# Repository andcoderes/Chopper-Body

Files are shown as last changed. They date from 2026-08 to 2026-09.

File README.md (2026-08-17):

# Chopper Body V2

## Acknowledgments

This firmware was strongly influenced by the [Amidala](https://github.com/thePunderWoman/Amidala) firmware by [thePunderWoman](https://github.com/thePunderWoman).

ESP32-based body controller for the Chopper robot. Controls drive motors, dome rotation, body servos, MP3 audio, and a bubble machine via ESP-NOW commands from the controller.

## Features

- **MDDS30 drive motors** — PWM Independent mode, differential steering
- **Cytron MD10C dome rotation** — bidirectional speed control
- **Pololu Maestro servos** — scripted body animations via Serial1
- **MP3 audio player** — serial protocol playback via Serial2
- **Bubbles relay** — on/off control
- **ESP-NOW** — encrypted communication with the controller
- **WiFi AP + OTA** — web interface at `chopper.body` for firmware updates
- **Safety timeout** — motors stop after 500ms without commands or on ESP-NOW disconnect

## ESP32 Pin Assignments

| Function | GPIO | Type | Notes |
|---|---|---|---|
| **MDDS30 IN1** (left dir) | 4 | Digital out | LOW = forward, HIGH = reverse. 10k pull-down on board |
| **MDDS30 AN1** (left speed) | 17 | LEDC PWM | 5 kHz, 8-bit. 10k pull-down on board |
| **MDDS30 IN2** (right dir) | 16 | Digital out | LOW = forward, HIGH = reverse. 10k pull-down on board |
| **MDDS30 AN2** (right speed) | 5 | LEDC PWM | 5 kHz, 8-bit. 10k pull-down on board |
| **Cytron MD10C DIR** (dome dir) | 14 | Digital out | 10k pull-down on board |
| **Cytron MD10C PWM** (dome speed) | 27 | LEDC PWM | 5 kHz, 8-bit. 10k pull-down on board |
| **Dome home sensor** | 26 | Digital in | A3144 hall-effect, 10k+20k divider |
| **Dome encoder A** | 25 | Digital in | 10k+20k divider |
| **Dome encoder B** | 33 | Digital in | 10k+20k divider |
| **Pololu Maestro TX** | 32 | Serial1 TX | 9600 baud |
| **Pololu Maestro RX** | 35 | Serial1 RX | Input-only. 1k + 2k voltage divider (5V -> 3.3V) |
| **MP3 Player TX** | 19 | Serial2 TX | 9600 baud |
| **MP3 Player RX** | 18 | Serial2 RX | 1k + 2k voltage divider (5V -> 3.3V) |
| **Bubbles relay** | 21 | Digital out | Relay module, active HIGH |
| **USB Debug TX** | 1 | Serial0 TX | 115200 baud |
| **USB Debug RX** | 3 | Serial0 RX | 115200 baud |

GPIO12 and GPIO13 (previously used for MDDS30) are intentionally left
unconnected — GPIO12 is an ESP32 boot-strapping pin (flash voltage select)
and stray HIGH signals on it during power-up can put the board in a reset
loop. GPIO22/23 (previously Maestro) and GPIO34 (previously dome encoder B)
are also now unused.

### MDDS30 DIP Switch Setting

`0b10110100` — PWM Independent mode. All three hardware UARTs remain free.

### Serial Port Allocation

| UART | GPIO TX | GPIO RX | Baud | Device |
|---|---|---|---|---|
| Serial0 | 1 | 3 | 115200 | USB debug console |
| Serial1 | 32 | 35 | 9600 | Pololu Maestro servo controller |
| Serial2 | 19 | 18 | 9600 | MP3 player module (Catalex-style, requires "select TF card" init) |

## Build

Requires [PlatformIO](https://platformio.org/).

Before your first build, set up ESP-NOW encryption keys — see
[Generating ESP-NOW keys](#generating-esp-now-keys) below. The build will
fail with a clear error if `.env` is missing.

```bash
# One-time setup: copy the template and fill in real keys
cp .env.example .env

# Compile firmware
pio run

# Upload to ESP32
pio run --target upload

# Run unit tests (native)
pio test -e native

# Monitor serial output
pio device monitor
```

## Project Structure

```
pcb/                                  # KiCad project (schematic, board, gerbers)
firmware/
  platformio.ini
  .env.example                       # Template for ESP-NOW keys — copy to .env
  partitions/ota_4MB.csv
  scripts/load_secrets.py            # Pre-build: .env -> include/secrets.h
  scripts/embed_web.py              # Pre-build: inlines CSS into HTML
  web/
    assets/common.css                # Shared styles
    index.html                       # Home page (info + links)
    update.html                      # OTA firmware upload page
  include/
    web_pages.h                      # AUTO-GENERATED by embed_web.py
    secrets.h                        # AUTO-GENERATED by load_secrets.py, gitignored
  src/
    config.h                         # Pin definitions, timeouts (keys come from secrets.h)
    main.cpp                         # Setup/loop, WiFi, command dispatch
    communication/
      MessageTypes.h                 # BodyCommand / BodyTelemetry structs
      EspNowController.h/.cpp        # ESP-NOW encrypted communication
    motor/
      MotorController.h/.cpp         # MDDS30 + L298N motor control
    servo/
      ServoController.h/.cpp         # Pololu Maestro body servos
    audio/
      AudioController.h/.cpp         # Serial MP3 player protocol
    web/
      WebController.h/.cpp           # WiFi AP, OTA updates, info API
      logger.h                       # Serial logging utility
  test/
    mocks/                           # Arduino/ESP32 mock headers
    test_message_types/              # Struct packing and field tests
    test_motor_controller/           # Drive mixing, dome, timeout tests
    test_audio_controller/           # MP3 protocol frame tests
    test_servo_controller/           # Animation state machine tests
    test_esp_now_controller/         # Connection timeout, dispatch tests
```

## ESP-NOW Protocol

### Controller -> Body (msgType = 3, 26 bytes)

| Field | Type | Description |
|---|---|---|
| msgType | int8 | Always 3 |
| status | int8 | 0 = buttons, 1 = movement, 2 = settings, -1 = connection |
| lx | int8 | Drive X axis: -100 to 100 |
| ly | int8 | Drive Y axis: -100 to 100 |
| domeSpeed | int8 | Dome rotation: -100 to 100 |
| audioTrack | uint8 | 0 = none, 1-255 = play track |
| volume | uint8 | 0-30 |
| bubbles | uint8 | 0 = off, 1 = on |
| button | char[8] | Servo button name (e.g. "y", "du") |
| macro | int16[4] | Servo macro IDs |
| connectionStatus | int8 | 0 = disconnected, 1 = connected |
| padding | uint8 | Alignment padding |

### Body -> Controller (msgType = 4, 8 bytes)

| Field | Type | Description |
|---|---|---|
| msgType | int8 | Always 4 |
| connected | uint8 | 1 if ESP-NOW link active |
| motorsActive | uint8 | 1 if drive/dome motors running |
| audioPlaying | uint8 | 1 if audio track playing |
| uptimeMs | uint32 | Milliseconds since boot |

## WiFi Access Point

- **SSID:** ChopperBody
- **IP:** 192.168.5.1
- **mDNS:** chopper-body.local
- **Pages:** `/` (home), `/update` (OTA)
- **API:** `/api/info` (JSON: version, uptime, heap, MAC)

## Generating ESP-NOW keys

This board talks to the other Chopper boards over encrypted ESP-NOW. Before
your first build, generate two 16-byte (128-bit) keys — a Primary Master Key
(PMK) and a Local Master Key (LMK) — and put them in a `.env` file
(gitignored, never commit it) at the project root:

```bash
cp .env.example .env
```

Generate two random 16-byte keys, each as 32 hex characters:

```bash
# Option 1: openssl
openssl rand -hex 16   # run twice — once for PMK_KEY, once for LMK_KEY

# Option 2: python
python3 -c "import secrets; print(secrets.token_hex(16))"
```

Edit `.env` and paste the values in:

```
PMK_KEY=<first random hex string>
LMK_KEY=<second random hex string>
```

**These two keys must be byte-for-byte identical across chopper body,
chopper head, and chopper receiver** — generate them once and copy the same
`.env` values into all three projects. Mismatched keys mean the boards can't
decrypt each other's ESP-NOW packets and the mesh will never connect.

`.env` also holds `CONTROLLER_MAC` — the controller's WiFi MAC address (as
hex, e.g. `C0CDD6CA29E0`), which must likewise be identical across all three
firmware projects — and `WIFI_AP_PASSWORD`, the password for this board's
local OTA-update access point (pick your own, at least 8 characters; unlike
the other values, this one doesn't need to match the other boards).

`scripts/load_secrets.py` runs automatically before every build (see
`platformio.ini`) and turns `.env` into `include/secrets.h`, which
`config.h` includes. Neither `.env` nor the generated `secrets.h` are
committed to git — the build fails with a clear error if `.env` is missing.

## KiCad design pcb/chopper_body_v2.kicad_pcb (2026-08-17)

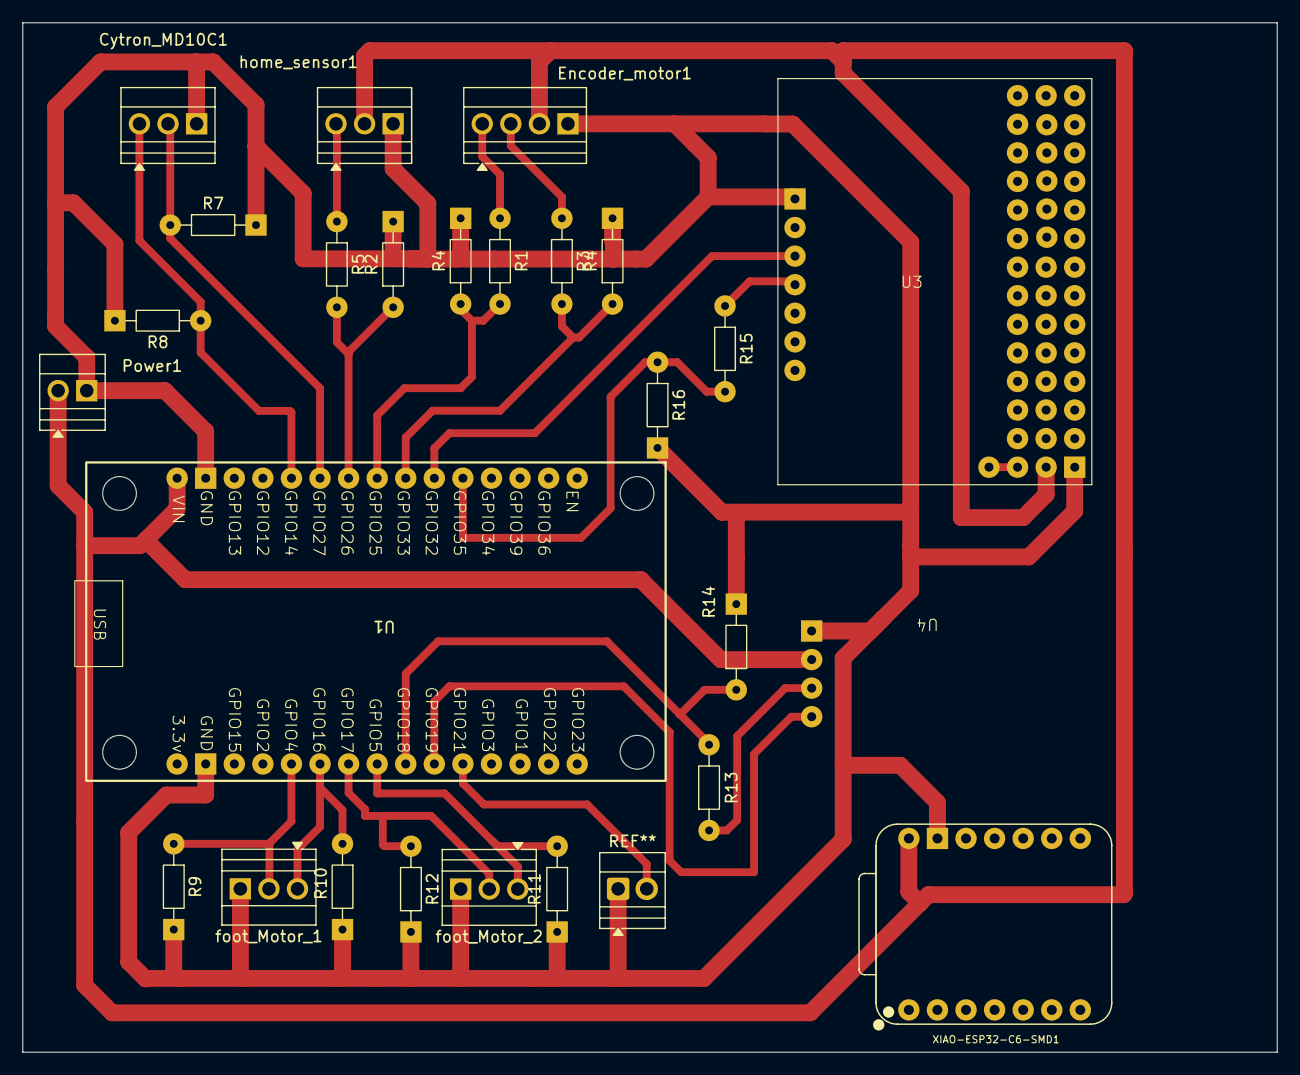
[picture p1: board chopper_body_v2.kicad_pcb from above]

Board: 2 copper layers, 111.5 x 91.5 mm, 26 parts (0 on the bottom side), 21 nets.

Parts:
Cytron_MD10C1: DIR_PWM_GND; TerminalBlock_Xinya_XY308-2.54-3P_1x03_P2.54mm_Horizontal
Encoder_motor1: motor_head_enc_a_enc_b_5v_GND; TerminalBlock_Xinya_XY308-2.54-4P_1x04_P2.54mm_Horizontal
Power1: 5v_GND; TerminalBlock_Xinya_XY308-2.54-2P_1x02_P2.54mm_Horizontal
R1, R3, R5, R7, R8, R9, R10, R11, R12: 10K; R_Axial_DIN0204_L3.6mm_D1.6mm_P7.62mm_Horizontal
R2, R4, R4#2: 20K; R_Axial_DIN0204_L3.6mm_D1.6mm_P7.62mm_Horizontal
R13, R15: 1K; R_Axial_DIN0204_L3.6mm_D1.6mm_P7.62mm_Horizontal
R14, R16: 2K; R_Axial_DIN0204_L3.6mm_D1.6mm_P7.62mm_Horizontal
U1: ESP32_30pin
U3: Pololu_Maestro_12
U4: audio_trigger
XIAO-ESP32-C6-SMD1: XIAO-ESP32-C6-SMD; XIAO-ESP32-C6-DIP
foot_Motor_1: IN1_IN2_GND; TerminalBlock_Xinya_XY308-2.54-3P_1x03_P2.54mm_Horizontal
foot_Motor_2: AN1_IN1_GND; TerminalBlock_Xinya_XY308-2.54-3P_1x03_P2.54mm_Horizontal
home_sensor1: sensor_5v_GND; TerminalBlock_Xinya_XY308-2.54-3P_1x03_P2.54mm_Horizontal

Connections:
+5V: Encoder_motor1.3, Power1.1, U1.1 (VIN), U3.V5In, U4.5V, XIAO-ESP32-C6-SMD1.14 (VBUS), home_sensor1.2
AN1: R12.1, U1.22 (GPIO17), foot_Motor_2.2
AN2: R11.1, U1.23 (GPIO5), foot_Motor_2.1
GND: Cytron_MD10C1.3, Encoder_motor1.4, Power1.2, R2.2, R4.2, R4#2.2, R7.2, R8.2, R9.2, R10.2, R11.2, R12.2, R14.2, R16.2, U1.2 (GND), U1.17 (GND), U3.GNDBoard, U3.GNDIn, U4.GND, XIAO-ESP32-C6-SMD1.13 (GND), foot_Motor_1.3, foot_Motor_2.3, home_sensor1.3
IN1: R9.1, U1.20 (GPIO4), foot_Motor_1.2
IN2: R10.1, U1.21 (GPIO16), foot_Motor_1.1
MD10PWM: Cytron_MD10C1.2, R7.1, U1.6 (GPIO27)
MD10_DIR: Cytron_MD10C1.1, R8.1, U1.5 (GPIO14)
audio_rx: U1.25 (GPIO19), U4.RX
audio_tx: R13.1, U4.TX
audio_tx_resistor: R13.2, R14.1, U1.24 (GPIO18)
encoder_a_resistor: R1.2, R4#2.1, U1.8 (GPIO25)
encoder_a_signal: Encoder_motor1.1, R1.1
encoder_b_resistor: R3.2, R4.1, U1.9 (GPIO33)
encoder_b_signal: Encoder_motor1.2, R3.1
home_sensor_resistant: R2.1, R5.2, U1.7 (GPIO26)
home_sensor_signal: R5.1, home_sensor1.1
pololu_rx: U1.10 (GPIO32), U3.Rx
pololu_tx: R15.1, U3.Tx
pololu_tx_resistor: R15.2, R16.1, U1.11 (GPIO35)
vin_pololu: U3.VSRV, U3.vin

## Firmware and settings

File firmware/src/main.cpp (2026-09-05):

#ifndef UNIT_TEST

#include <Arduino.h>
#include <WiFi.h>
#include <esp_wifi.h>
#include <cstring>
#include "config.h"
#include "communication/EspNowController.h"
#include "communication/MessageTypes.h"
#include "motor/MotorController.h"
#include "dome/DomeController.h"
#include "servo/ServoController.h"
#include "audio/AudioController.h"
#include "web/WebController.h"
#include "web/logger.h"

EspNowController espNow;
MotorController motors;
DomeController dome;
ServoController servo;
AudioController audio;
WebController webController;

bool apActive_ = false;
bool apStartRequested_ = false;
unsigned long bootTime_ = 0;

// Starts the AP + web/captive-portal server. Off by default; only called
// once one of the AP-start conditions is met (see loop()).
void startAP() {
    if (apActive_) return;

    WiFi.softAP(WIFI_AP_SSID, WIFI_AP_PASSWORD);
    WiFi.softAPConfig(IPAddress(192,168,5,1), IPAddress(192,168,5,1), IPAddress(255,255,255,0));

    webController.setDomeController(&dome);
    webController.setup();

    apActive_ = true;
    logAll("AP started, IP: %s", WiFi.softAPIP().toString().c_str());
}

void onCommand(const BodyCommand& cmd) {
    switch (cmd.status) {
        case STATUS_MOVEMENT:
            logAll("ESP-NOW RX: move lx=%d ly=%d dome=%d", cmd.lx, cmd.ly, cmd.domeSpeed);
            motors.setDrive(cmd.ly, -cmd.lx);
            // Dome calibration drives the dome motor itself via dome.loop();
            // an RF movement command here would fight that write.
            if (!dome.isCalibrating()) {
                motors.setDome(cmd.domeSpeed);
            }
            break;

        case STATUS_BUTTONS: {
            logAll("ESP-NOW RX: button='%s' macro=[%d,%d,%d,%d]",
                   cmd.button, cmd.macro[0], cmd.macro[1], cmd.macro[2], cmd.macro[3]);
            int16_t macro[4];
            memcpy(macro, cmd.macro, sizeof(macro));
            servo.animate(cmd.button, macro, 4);
            break;
        }

        case STATUS_CONNECTION:
            logAll("ESP-NOW RX: connection status=%d", cmd.connectionStatus);
            if (cmd.connectionStatus == 0) {
                motors.stopAll();
            }
            break;

        case STATUS_SETTINGS:
            logAll("ESP-NOW RX: settings track=%u vol=%u bubbles=%u",
                   cmd.audioTrack, cmd.volume, cmd.bubbles);
            audio.setVolume(cmd.volume);
            break;

        case STATUS_AP_CONTROL:
            logAll("ESP-NOW RX: AP control requested=%u", cmd.apRequested);
            if (cmd.apRequested) {
                apStartRequested_ = true;
            }
            break;

        default:
            logAll("ESP-NOW RX: unknown status=%d", cmd.status);
            break;
    }

    // Audio and bubbles are handled regardless of status
    if (cmd.audioTrack > 0) {
        audio.playTrack(cmd.audioTrack);
    }
    // cmd.bubbles is the current toggle state from the receiver (see
    // CommandParser), re-stamped onto every packet — just mirror it.
    if (cmd.bubbles) {
        logAll("starting bubbles");
    } else {
        logAll("bubble off");
    }
    digitalWrite(PIN_BUBBLES, cmd.bubbles ? HIGH : LOW);
}

void setup() {
    // Drive every motor pin to a safe stopped state before anything else runs.
    // Until this executes they are undriven inputs; the MDDS30 / MD10C read the
    // floating level as a command and creep a motor during the boot delay below
    // (worst on GPIO16/17, which also toggle at boot on WROVER modules).
    motors.setup();

    // Bubbles relay — same floating-input risk, safe it early too.
    pinMode(PIN_BUBBLES, OUTPUT);
    digitalWrite(PIN_BUBBLES, LOW);

    bootTime_ = millis();

    Serial.begin(115200);
    delay(500);

    dome.setup(motors);
    servo.setup();
    audio.setup();

    // WiFi: AP+STA mode for ESP-NOW + web server coexistence.
    // AP itself stays off (WiFi.softAP not called) until an AP-start
    // condition is met in loop() — see startAP().
    WiFi.mode(WIFI_AP_STA);
    esp_wifi_set_ps(WIFI_PS_NONE);

    espNow.setup();
    espNow.setCommandCallback(onCommand);

    logAll("Chopper V2 Body ready");
}

void loop() {
    // Safety: stop motors on timeout or ESP-NOW disconnect
    motors.checkTimeout();
    if (!espNow.isConnected()) {
        motors.stopAll();
    }

    // Dome encoder / calibration
    dome.loop();

    // Update telemetry state
    espNow.setMotorsActive(motors.isActive());
    espNow.setAudioPlaying(audio.isPlaying());

    // Process ESP-NOW messages and send heartbeat
    espNow.loop();

    // Log any bytes the MP3 module sends back (diagnostics)
    audio.loop();

    // Servo connection check
    if (!servo.isReady()) {
        servo.checkConnection();
    }

    // AP is off by default. Start it if:
    //  - the mesh (ESP-NOW) link hasn't connected within AP_START_TIMEOUT_MS
    //    of boot, or
    //  - a peer over the mesh explicitly requested it (STATUS_AP_CONTROL)
    if (!apActive_) {
        bool meshTimedOut = (millis() - bootTime_ >= AP_START_TIMEOUT_MS) && !espNow.isConnected();
        if (apStartRequested_ || meshTimedOut) {
            startAP();
        }
    }

    // Web server (only serving once the AP is up)
    if (apActive_) {
        webController.loop();
    }
}

#endif // UNIT_TEST

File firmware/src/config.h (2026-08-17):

#pragma once
#include <Arduino.h>

// --- MDDS30 drive motor pins (PWM Independent mode, DIP: 0b10110100) ---
// External pull-down resistors required on all 4 pins: while the ESP32 is
// powering on/off (or resetting) these GPIOs float/default HIGH before
// setup() runs pinMode()/ledcAttachPin(), which the MDDS30 can read as a
// drive command and briefly engage the motors.
#define PIN_MDDS_IN1     4   // Left motor direction (LOW=fwd, HIGH=rev)
#define PIN_MDDS_AN1    17   // Left motor speed (LEDC PWM, 5kHz 8-bit)
#define PIN_MDDS_IN2    16   // Right motor direction (LOW=fwd, HIGH=rev)
#define PIN_MDDS_AN2     5   // Right motor speed (LEDC PWM, 5kHz 8-bit)

// --- Dome encoder + home sensor ---
#define PIN_DOME_ENC_A  25   // Encoder channel A (10k+20k divider)
#define PIN_DOME_ENC_B  33   // Encoder channel B (10k+20k divider)
#define PIN_DOME_HOME   26   // A3144 hall-effect home sensor (HiLetgo module, 10k+20k divider)
#define DOME_ENCODER_CPR 3200 // Counts per motor output shaft revolution (64 CPR * 50:1)
#define DOME_CALIBRATION_SPEED 40 // PWM % for calibration spin
#define DOME_CALIBRATION_TIMEOUT_MS 15000 // Abort calibration if home sensor never fires (safety cutoff)

// --- Cytron MD10C dome rotation motor pins ---
// External 10k pull-down resistors required on both pins (same reason as MDDS30).
#define PIN_DOME_DIR    14   // Dome direction (LOW=fwd, HIGH=rev)
#define PIN_DOME_PWM    27   // Dome speed (LEDC PWM, 5kHz 8-bit)

// --- Pololu Maestro servo controller (Serial1) ---
#define PIN_MAESTRO_TX  32   // Serial1 TX -> Maestro RX (9600 baud)
#define PIN_MAESTRO_RX  35   // Serial1 RX <- Maestro TX (1k+2k divider)

// --- MP3 player (Serial2) ---
#define PIN_MP3_TX      19   // Serial2 TX -> MP3 RX (9600 baud)
#define PIN_MP3_RX      18   // Serial2 RX <- MP3 TX (1k+2k divider)

// --- Bubbles relay ---
#define PIN_BUBBLES     21   // On/off relay module

// --- Secrets (ESP-NOW keys, controller MAC, WiFi AP password) ---
#ifdef UNIT_TEST
// Dummy values for native unit tests — no real ESP-NOW traffic or AP off-device.
static const uint8_t PMK_KEY[16] = {0};
static const uint8_t LMK_KEY[16] = {0};
static const uint8_t CONTROLLER_MAC[6] = {0};
#define WIFI_AP_PASSWORD "test"
#else
#include "secrets.h"  // defines PMK_KEY, LMK_KEY, CONTROLLER_MAC, WIFI_AP_PASSWORD — generated from .env, see README
#endif

// --- Timing constants ---
#define HEARTBEAT_INTERVAL_MS   1000   // How often to send telemetry
#define CONNECTION_TIMEOUT_MS   5000   // No data = disconnected
#define MOTOR_TIMEOUT_MS         500   // Stop motors if no command
#define AP_START_TIMEOUT_MS     3000   // Start AP if mesh not connected by this long after boot

// --- WiFi AP for web server ---
#define WIFI_AP_SSID     "ChopperBody"
// WIFI_AP_PASSWORD comes from secrets.h (generated from .env, see README)

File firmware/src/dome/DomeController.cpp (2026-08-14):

#include "DomeController.h"
#include "../motor/MotorController.h"
#include "../web/logger.h"

volatile int32_t DomeController::encoderCount_ = 0;
volatile bool DomeController::homeTriggered_ = false;

// Guards encoderCount_, shared between onEncoderA() (ISR) and loop()/
// getEncoderCount() (Arduino task). Same portMUX_TYPE pattern used in
// EspNowController for its own ISR/task-shared state.
static portMUX_TYPE encoderMux_ = portMUX_INITIALIZER_UNLOCKED;

void IRAM_ATTR DomeController::onEncoderA() {
    if (digitalRead(PIN_DOME_ENC_B)) {
        encoderCount_ = encoderCount_ - 1;
    } else {
        encoderCount_ = encoderCount_ + 1;
    }
}

void IRAM_ATTR DomeController::onHomeTriggered() {
    homeTriggered_ = true;
}

void DomeController::setup(MotorController& motors) {
    motors_ = &motors;
    encoderCount_ = 0;
    homeTriggered_ = false;
    gearRatio_ = 0.0f;
    state_ = IDLE;

    pinMode(PIN_DOME_ENC_A, INPUT);
    pinMode(PIN_DOME_ENC_B, INPUT);
    pinMode(PIN_DOME_HOME, INPUT);

    attachInterrupt(digitalPinToInterrupt(PIN_DOME_ENC_A), onEncoderA, RISING);
    attachInterrupt(digitalPinToInterrupt(PIN_DOME_HOME), onHomeTriggered, FALLING);

    logAll("Dome encoder + home sensor initialized");
}

void DomeController::startCalibration() {
    if (state_ != IDLE) return;
    homeTriggered_ = false;
    state_ = SEEKING_HOME;
    calibrationStartTime_ = millis();
    // Speed is constant across SEEKING_HOME and ROTATING, so it only needs
    // to be written once here instead of every loop() iteration.
    motors_->setDome(DOME_CALIBRATION_SPEED);
    logAll("Dome calibration: seeking home");
}

bool DomeController::checkCalibrationTimeout(const char* phase) {
    if (millis() - calibrationStartTime_ < DOME_CALIBRATION_TIMEOUT_MS) return false;
    logAll("Dome calibration: timed out %s, aborting", phase);
    motors_->setDome(0);
    state_ = IDLE;
    return true;
}

void DomeController::loop() {
    switch (state_) {
        case IDLE:
            break;

        case SEEKING_HOME:
            if (checkCalibrationTimeout("seeking home")) break;
            if (homeTriggered_) {
                homeTriggered_ = false;
                portENTER_CRITICAL(&encoderMux_);
                encoderCount_ = 0;
                portEXIT_CRITICAL(&encoderMux_);
                state_ = ROTATING;
                calibrationStartTime_ = millis();  // fresh budget for the rotation phase
                logAll("Dome calibration: home found, counting");
            }
            break;

        case ROTATING:
            if (checkCalibrationTimeout("completing rotation")) break;
            if (homeTriggered_) {
                homeTriggered_ = false;
                portENTER_CRITICAL(&encoderMux_);
                int32_t count = encoderCount_;
                portEXIT_CRITICAL(&encoderMux_);
                gearRatio_ = (float)abs(count) / DOME_ENCODER_CPR;
                state_ = DONE;
            }
            break;

        case DONE:
            motors_->setDome(0);
            logAll("Dome calibration done: %ld ticks, ratio=%.2f",
                   (long)abs(encoderCount_), gearRatio_);
            state_ = IDLE;
            break;
    }
}

bool DomeController::isCalibrating() const {
    return state_ != IDLE;
}

float DomeController::getGearRatio() const {
    return gearRatio_;
}

int32_t DomeController::getEncoderCount() const {
    int32_t count;
    portENTER_CRITICAL(&encoderMux_);
    count = encoderCount_;
    portEXIT_CRITICAL(&encoderMux_);
    return count;
}

float DomeController::getRotations() const {
    return (float)getEncoderCount() / DOME_ENCODER_CPR;
}

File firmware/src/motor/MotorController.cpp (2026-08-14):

#include "MotorController.h"
#include "../web/logger.h"

void MotorController::setup() {
    // MDDS30 direction pins
    pinMode(PIN_MDDS_IN1, OUTPUT);
    pinMode(PIN_MDDS_IN2, OUTPUT);

    // MDDS30 PWM speed channels (5kHz, 8-bit resolution)
    ledcAttach(PIN_MDDS_AN1, 5000, 8);
    ledcAttach(PIN_MDDS_AN2, 5000, 8);

    // MD10C dome direction pin
    pinMode(PIN_DOME_DIR, OUTPUT);

    // MD10C dome PWM speed channel (5kHz, 8-bit resolution)
    ledcAttach(PIN_DOME_PWM, 5000, 8);

    stopAll();
    logAll("Motors initialized");
}

void MotorController::setMotor(uint8_t dirPin, uint8_t pwmPin, int speed) {
    speed = constrain(speed, -100, 100);
    if (speed == 0) {
        digitalWrite(dirPin, LOW);
        ledcWrite(pwmPin, 0);
    } else {
        digitalWrite(dirPin, speed < 0 ? HIGH : LOW);
        ledcWrite(pwmPin, (uint32_t)(abs(speed) * 255 / 100));
    }
}

void MotorController::setDrive(int8_t lx, int8_t ly) {
    // Differential drive mixing
    int left  = constrain((int)ly + (int)lx, -100, 100);
    int right = constrain((int)ly - (int)lx, -100, 100);

    setMotor(PIN_MDDS_IN1, PIN_MDDS_AN1, left);
    setMotor(PIN_MDDS_IN2, PIN_MDDS_AN2, right);

    driveActive_ = (left != 0 || right != 0);
    lastCommandTime_ = millis();
}

void MotorController::setDome(int8_t speed) {
    setMotor(PIN_DOME_DIR, PIN_DOME_PWM, speed);
    domeActive_ = (speed != 0);
    lastCommandTime_ = millis();
}

void MotorController::stopAll() {
    setMotor(PIN_MDDS_IN1, PIN_MDDS_AN1, 0);
    setMotor(PIN_MDDS_IN2, PIN_MDDS_AN2, 0);
    setMotor(PIN_DOME_DIR, PIN_DOME_PWM, 0);
    driveActive_ = false;
    domeActive_ = false;
}

bool MotorController::isActive() const {
    return driveActive_ || domeActive_;
}

void MotorController::checkTimeout() {
    if ((driveActive_ || domeActive_) && (millis() - lastCommandTime_ >= MOTOR_TIMEOUT_MS)) {
        logAll("Motor timeout - stopping");
        stopAll();
    }
}

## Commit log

2026-08-14 Initial commit: Chopper body firmware + PCB
    ESP32 body controller firmware (motors, dome, servo, audio, ESP-NOW,
    web/OTA) and the KiCad PCB design.
    [chopper_body_v2-B_Cu.gbr, chopper_body_v2-B_Mask.gbr, chopper_body_v2-B_Paste.gbr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]
2026-08-14 Flatten pcb/ folder structure
    KiCad project files now live directly under pcb/ instead of a nested
    pcb/chopper_body_v2/ subfolder.
    [chopper_body_v2-B_Cu.gbr, chopper_body_v2-B_Mask.gbr, chopper_body_v2-B_Paste.gbr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]
2026-08-14 Fix motor pin mapping, bubbles toggle logging, and volatile warning
    - Remap MDDS30 pins to match actual PCB wiring: AN1=27, AN2=14, IN1=13
    (IN2 stays 12)
    - Log bubbles relay state transitions in onCommand()
    - Avoid deprecated ++/-- on volatile encoderCount_ in DomeController ISR
    [DomeController.cpp, config.h, main.cpp]
2026-08-17 Move drive motor pins off GPIO12/13, resync firmware pin map to PCB
    Rerouted MDDS30 drive motors, dome I/O, Maestro, MP3, and bubbles relay
    to new ESP32 pins on the PCB, primarily to get off GPIO12 (a boot-
    strapping pin whose flash-voltage strap could cause reset loops if
    pulled high during power-up). Updated config.h and the README pin
    tables to match the new PCB copper.
    [chopper_body_v2-B_Cu.gbr, chopper_body_v2-B_Mask.gbr, chopper_body_v2-B_Paste.gbr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]
2026-09-05 Fix drive-axis mapping, boot motor twitch, port body servo animations
    main.cpp:
    - Correct STATUS_MOVEMENT mixing to setDrive(cmd.ly, -cmd.lx) so the
    controller's transposed stick axes map to forward/back = up/down and
    turn = left/right.
    - Run motors.setup() (and safe the bubbles relay) as the first thing in
    setup(), before Serial.begin()/delay(500), so the MDDS30/MD10C pins are
    driven low immediately instead of floating for ~0.5s and creeping a
    motor at boot.
    ServoController:
    - Replace the head-derived arm-out gating (checkAnimation/execute) with the
    C1-10P BodyController model: 5 keys (l1, r1, a, 102, 107), each cycling
    its own variable-length script sequence; stopScript() be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
    [ServoController.cpp, main.cpp, test_servo_controller.cpp]
2026-09-05 Update editor extension recommendations and PCB DRC rules
    - .vscode/extensions.json: recommend esp-decoder and pioarduino IDE.
    - chopper_body_v2.kicad_pro: relax DRC min clearance (0.4->0.0), min hole
    clearance (0.3->0.25), and min track width (0.7->0.5) for the current
    manufacturing constraints.
